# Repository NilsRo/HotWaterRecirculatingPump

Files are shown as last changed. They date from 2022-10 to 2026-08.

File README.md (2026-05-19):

# Recirculation pump automated
How to optimize your water heating with an ESP32.

The project follows the ideas of https://github.com/MakeMagazinDE/Zirkulationspumpensteuerung and http://www.kabza.de/MyHome/CircPump/CirculationPump.php to control the hot water recirculation pump (Warmwasserzirkulationspumpe) via two temperature sensors comparing the warm water flow and return temperature. This saves electricity and thermal energy as the circulation will by done on request and not countinuously.

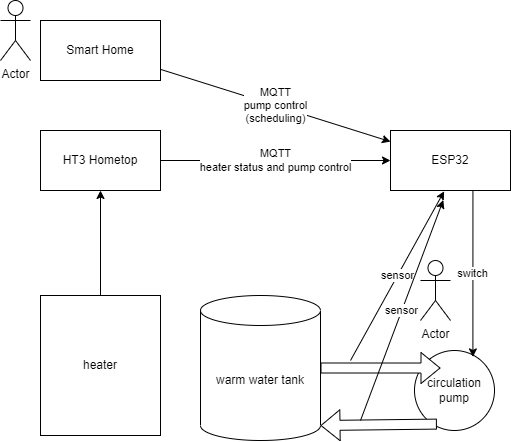
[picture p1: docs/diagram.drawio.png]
diagram


In the HT3 warm water diagram you see the period without warm water taking is flattend so the heater does heatup fewer.

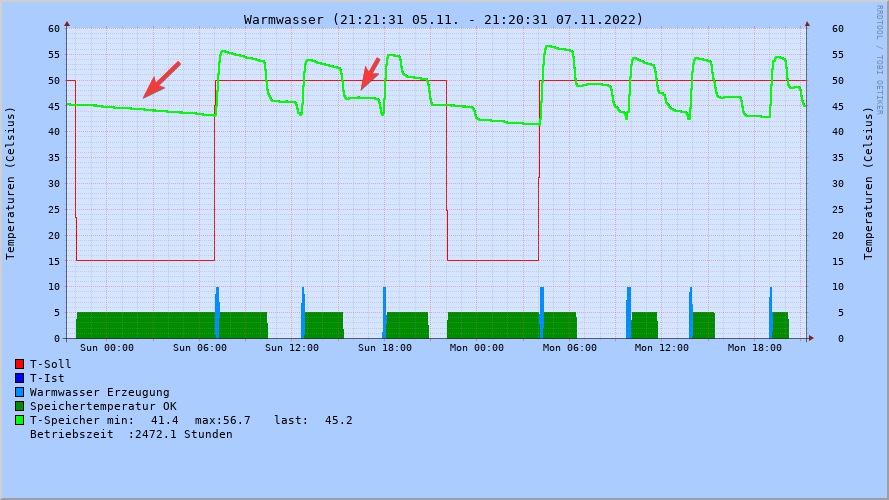
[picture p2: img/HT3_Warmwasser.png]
warm water log


## Featurelist
* Managing the pump via flow and return temperature
* MQTT publishing to get logging information
* MQTT subscription for your smart home and to use heater information like provided by https://github.com/norberts1/hometop_HT3
* Realtime clock for desinfection and logging
* SSD1306 OLED to view status information
* Guided setup to avoid storing WiFi password, etc. in the code
* 2 channel relay to add e.g. a magnetic vent later

## [Hardware](docs/schema.pdf)
* Wemos D1 Mini ESP32
* Standard Arduino/Raspberry 2-channel relay with optokoppler
* [BOM](docs/HotWaterRecirculatingPump.csv)
* STL for [case](docs/Warmwasserpumpe.stl) and [cover](docs/Warmwasserpumpe(2).stl)

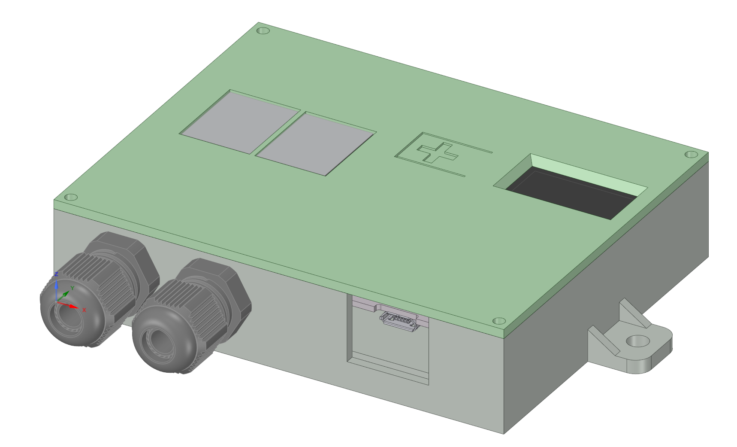
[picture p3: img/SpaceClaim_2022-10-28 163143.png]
Case

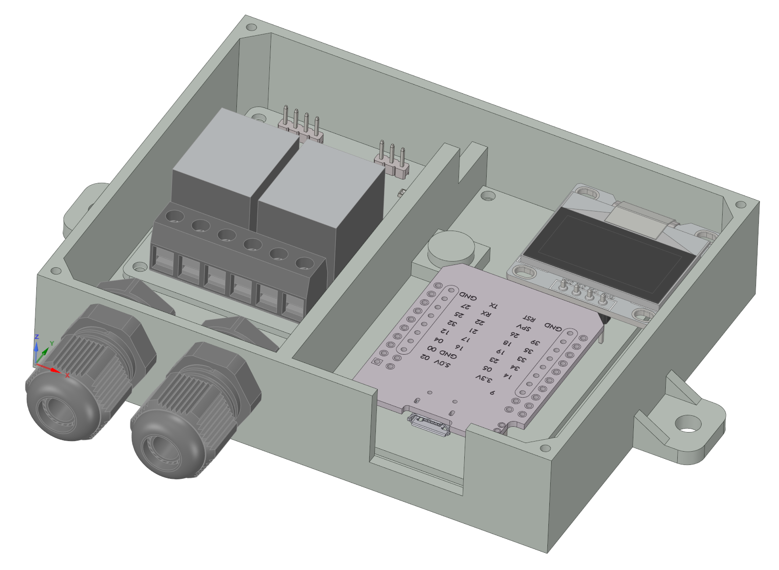
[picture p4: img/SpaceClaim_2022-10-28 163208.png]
Case opened

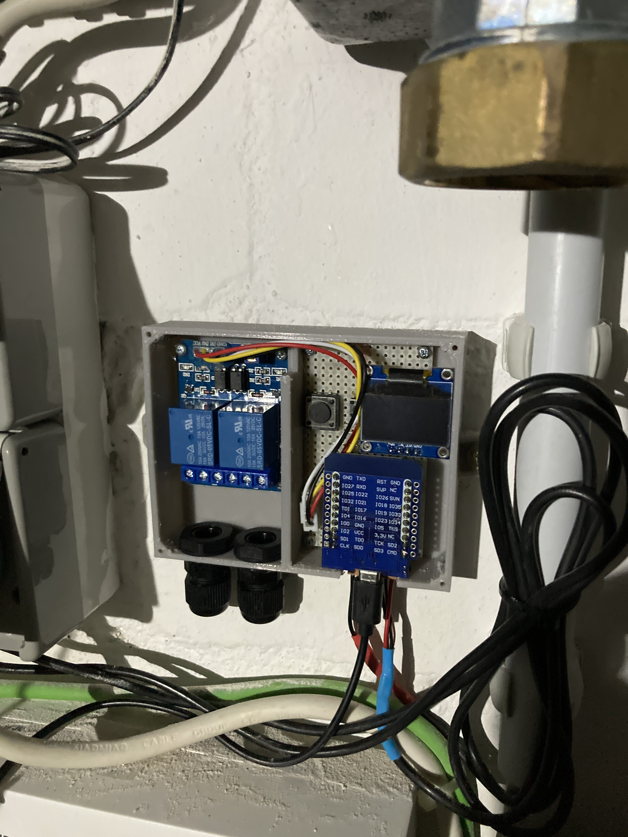
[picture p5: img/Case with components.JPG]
Case with components mounted


## Mounting
The flow sensor have to be mounted 50cm away from the hot water reserviour. The return sensor near the end of the return pipe but not side by side to the reserviour. 

# Software
On first start the thing will open an Access Point named "Zirkulationspumpe" to provide the setup interface. The interface is still available after the device is connected so you can change everything later. But at first the firmware has to be uploaded. You can compile your own version or use the firmware provided in the releases.

1. Do the system configuration and set things name (hostname), AP password (if WiFi connection is lost) and WiFi credentials for your network.
2. MQTT configuration (optional)
   1. publish the following topics (folder structure can be changed):
      * "ww/ht/dhw_Tflow_measured": out temperature of the warm water
      * "ww/ht/dhw_Treturn": return temperature of the warm water circulation
      * "ww/ht/dhw_Tdelta": difference detected in the 5s time window
      * "ww/ht/Tint": system internal temperature
      * "ww/ht/dhw_pump_circulation": pump is running or not
      * "ww/ht/dhw_valve_opened": valve is currently open (true/false)
      * "ww/ht/dhw_valve_sec_opened": how many seconds the valve has been open
      * "ww/ht/dhw_valve_sec_to_refill": seconds until a refill was neccessary. Could be used for alerting purposes if there is a leakage.
      * "ww/ht/dhw_valve_pressure_avg": average system pressure value
      * "ww/ht/status": availability of the system is connected to mqtt broker (Online) or not (Offline)
      * "ww/ht/wifi": wifi related infos like signal quality
      * "ww/ht/sysinfo": status of the system showing the actual mode as Json
        * mode 
          * auto - automatic mode
          * manual - control the pump via the button. The 24h timer to clean the pipes is still running.
        * state
          * heater on - temperature is watched and pump is starting automatically or by MQTT triggers
          * heater off - pump can be started by MQTT triggers
          * desinfection - Desinfection is running, all triggers are blocked until the desinfection is finished by MQTT trigger
          * emergency - some sort of problem detected like with DS18B20. The pump will start by a timer regularly.
      * "ww/ht/info": system information as text
   2. subscribe to heater topics
      * heater status topic (e.g. ht3/hometop/ht/hc1_Tniveau): if the value is matched the system switches to automatic mode. If it is not matched the pump is off and reacts on desinfection and manual starts only.
      * external pump start topic (e.g. ht3/hometop/ht/dhw_pump_circulation):  The event is triggered if the message contains the value set in the configuration. The pump will swtched off if the desired return temperature is reached. Could be used to have a dump switch with HT3 and avoids buying a second IPM module for water pump (automatic mode should be disabled) or much better you can trigger the pump from your smart home or something more advanced.
      * thermal desinfection topic (e.g. ht3/hometop/ht/dhw_thermal_desinfection): if the value is matched the pump will switch on infinitly until another value is received on this topic. This can be used for desinfection topics. If desinfection is switched off the pump will still run until the necessary temperature is reached on the return pipe to guarantee the desinfection of the whole pipe.
3. NTP configuration to get RTC infos for logging (default is fine for german timezone)
4. Temperature configuration to map DS18B20 sensors detected
5. Define your return temperature to switch off when the water is gone through the whole circulation pipe.
6. button short press to swtich screen, button long press for testing the relay/pump.

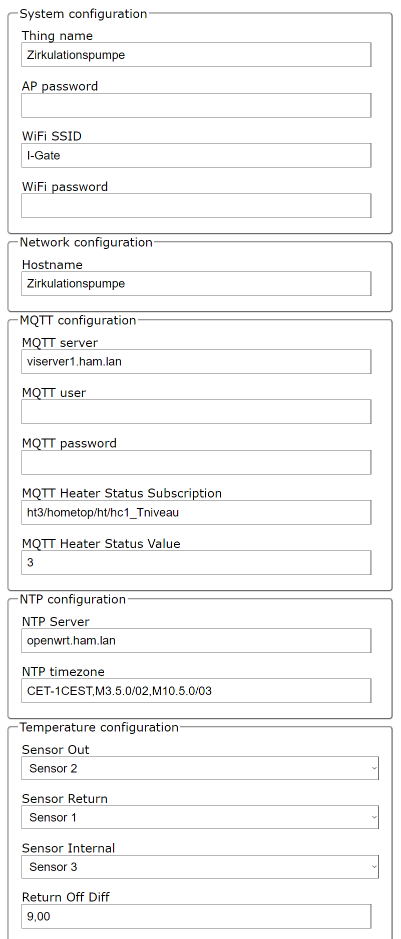
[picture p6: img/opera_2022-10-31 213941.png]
config page


## OLED infos
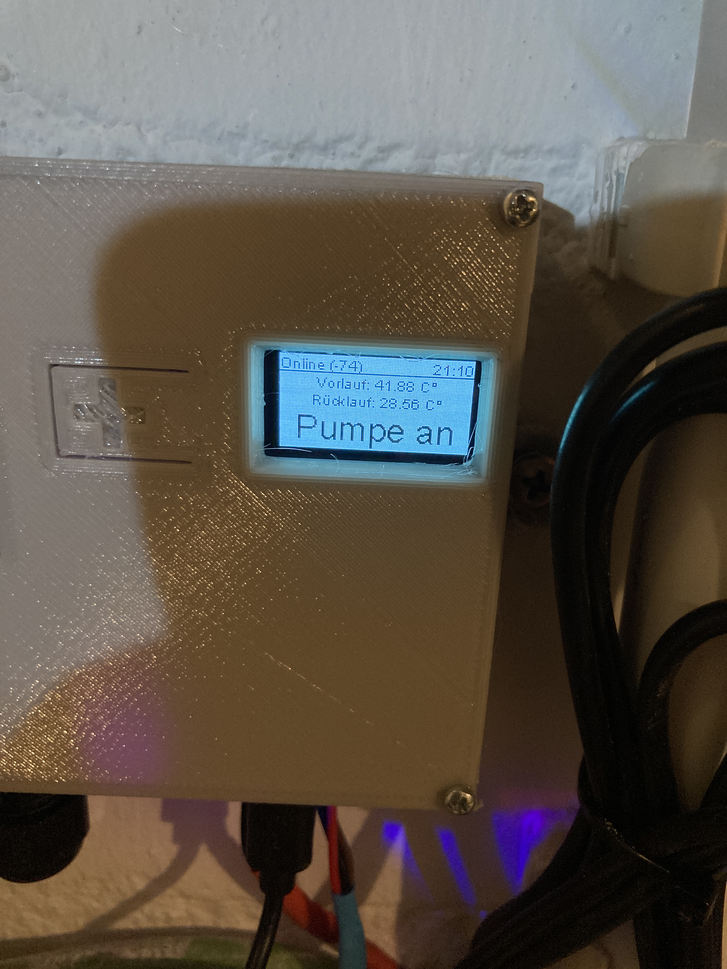
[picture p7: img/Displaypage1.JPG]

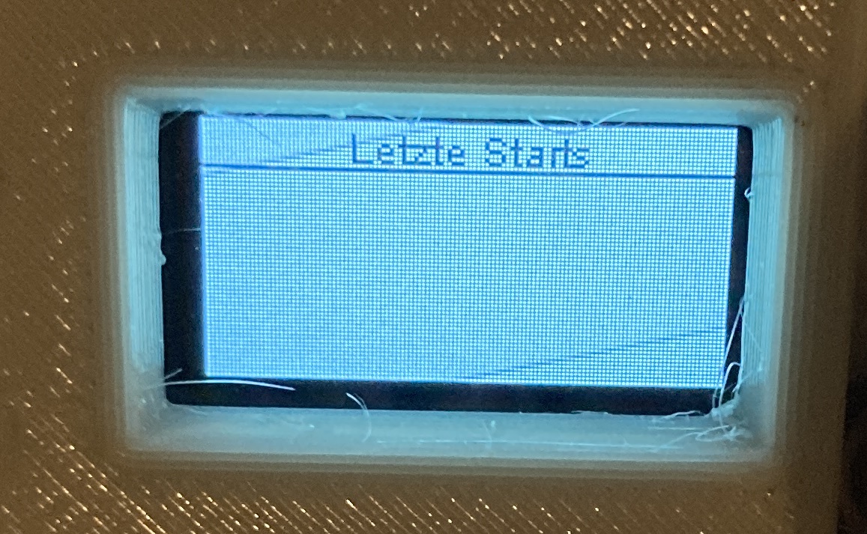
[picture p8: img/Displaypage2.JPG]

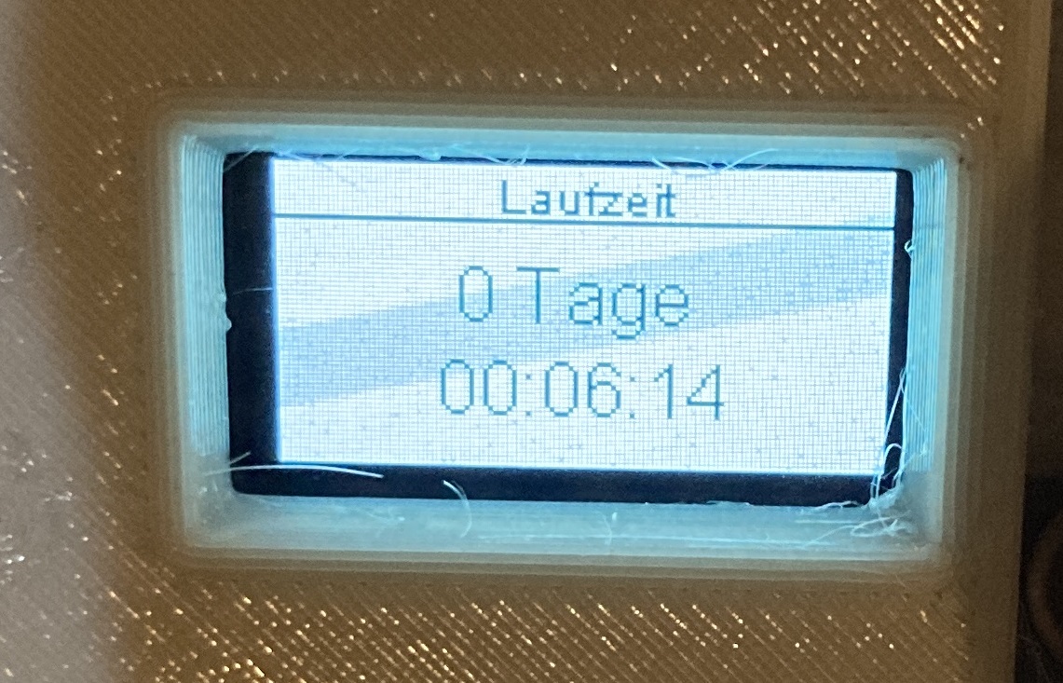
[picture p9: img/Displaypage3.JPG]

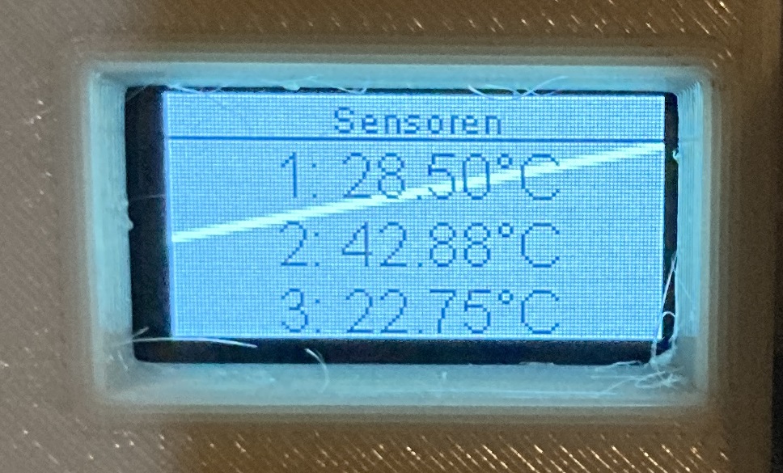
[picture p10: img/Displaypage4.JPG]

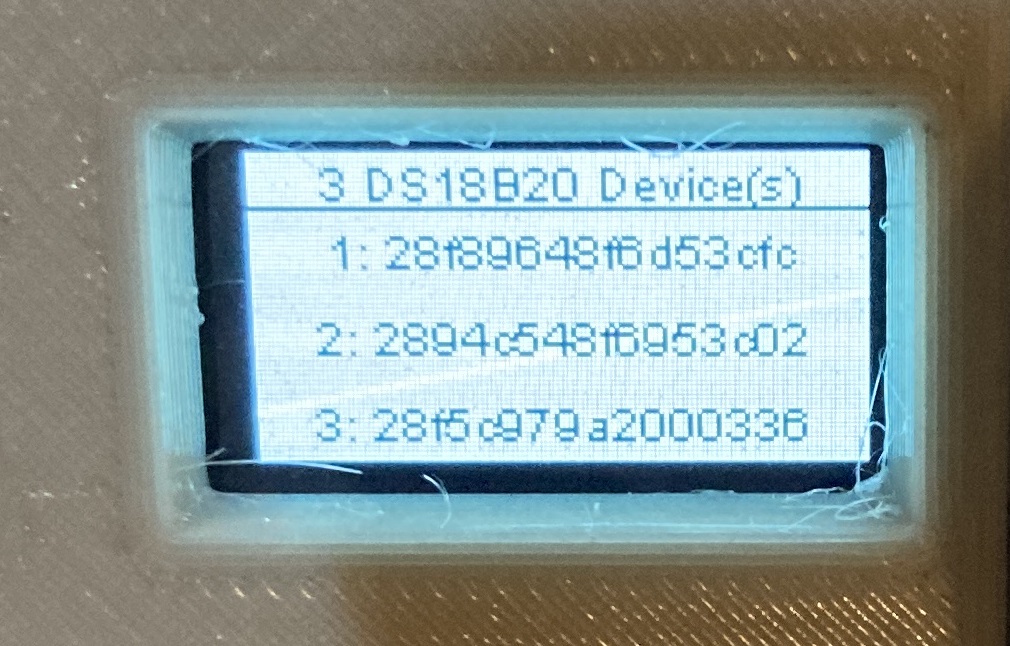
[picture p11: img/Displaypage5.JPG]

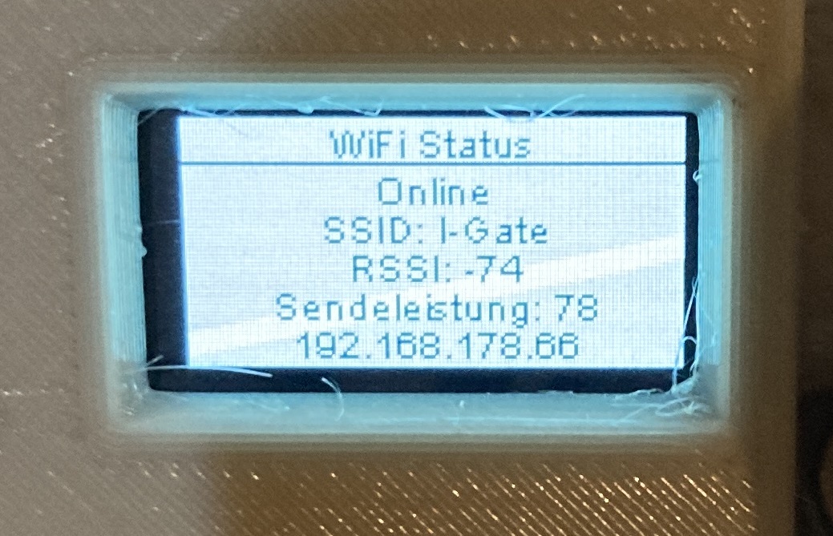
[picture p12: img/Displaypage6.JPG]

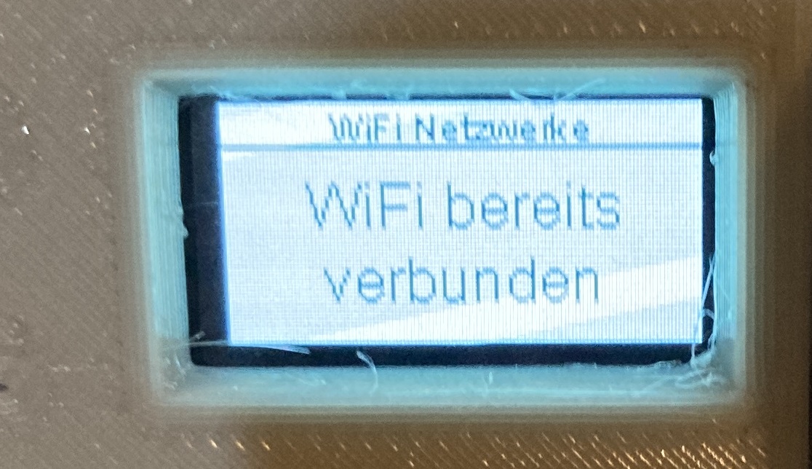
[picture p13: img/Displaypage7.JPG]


# Tips
* Increase the pumps flow to the maximum that the water goes through the pipes as fast as possible.
* Setup special schedules via a smart home (MQTT) if you like to have warm water on request (e.g. by phone) or at a specific time.
* second relay channel is actually unused - suggest how to use it if you need
* If you are using separate networks for IoT devices it is not possible to flash the device with ArduinoOTA as it using broadcast messages that are usually dropped in the firewall. For that setup you should use HTTP upload in the config page to upload the firmware.bin.

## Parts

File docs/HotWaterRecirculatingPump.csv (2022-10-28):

Source: | C:\Users\nrott\Documents\Sync\HomeNils\Modellbau\KiCad\HotWaterRecirculatingPump\HotWaterRecirculatingPump\HotWaterRecirculatingPump.kicad_sch
Date: | 28.10.2022 16:19:44
Tool: | Eeschema (6.0.8)
Generator: | C:\Program Files\KiCad\6.0\bin\scripting\plugins/bom_csv_grouped_by_value.py
Component Count: | 12
Individual Components:
Item | Qty | Reference(s) | Value | LibPart | Footprint | Datasheet
 |  | C1 | 10uF | Device:C |  | ~
 |  | C2 | 470uF | Device:C_Polarized |  | ~
 |  | J1 | Dual Relay | Connector:Conn_01x04_Male | Connector_PinHeader_2.54mm:PinHeader_1x04_P2.54mm_Vertical | ~
 |  | J2 | DS18B20 | Connector:Conn_01x03_Male | Connector_PinHeader_2.54mm:PinHeader_1x03_P2.54mm_Vertical | ~
 |  | J3 | DS18B20 | Connector:Conn_01x03_Male | Connector_PinHeader_2.54mm:PinHeader_1x03_P2.54mm_Vertical | ~
 |  | J4 | BUTTON_LED | Connector:Conn_01x04_Male | Connector_PinHeader_2.54mm:PinHeader_1x04_P2.54mm_Vertical | ~
 |  | LCD1 | SSD1306 | SSD1306:SSD1306 | SSD1306:128x64OLED
 |  | R1 | 1kOhm | Device:R | Resistor_THT:R_Axial_DIN0207_L6.3mm_D2.5mm_P10.16mm_Horizontal | ~
 |  | R2 | 1kOhm | Device:R | Resistor_THT:R_Axial_DIN0207_L6.3mm_D2.5mm_P10.16mm_Horizontal | ~
 |  | SW1 | SW_WIFI_CONF | Switch:SW_Push | Button_Switch_THT:SW_PUSH_6mm_H4.3mm | ~
 |  | U1 | DS18B20 | Sensor_Temperature:DS18B20 | Package_TO_SOT_THT:TO-92_Inline | http://datasheets.maximintegrated.com/en/ds/DS18B20.pdf
 |  | U3 | mini_esp32 | ESP32_mini:mini_esp32 | ESP32_mini:ESP32_mini
Collated Components:
Item | Qty | Reference(s) | Value | LibPart | Footprint | Datasheet
1 | 1 | C1 | 10uF | Device:C |  | ~
2 | 1 | C2 | 470uF | Device:C_Polarized |  | ~
3 | 1 | J1 | Dual Relay | Connector:Conn_01x04_Male | Connector_PinHeader_2.54mm:PinHeader_1x04_P2.54mm_Vertical | ~
4 | 2 | J2, J3 | DS18B20 | Connector:Conn_01x03_Male | Connector_PinHeader_2.54mm:PinHeader_1x03_P2.54mm_Vertical | ~
5 | 1 | J4 | BUTTON_LED | Connector:Conn_01x04_Male | Connector_PinHeader_2.54mm:PinHeader_1x04_P2.54mm_Vertical | ~
6 | 1 | LCD1 | SSD1306 | SSD1306:SSD1306 | SSD1306:128x64OLED
7 | 2 | R1, R2 | 1kOhm | Device:R | Resistor_THT:R_Axial_DIN0207_L6.3mm_D2.5mm_P10.16mm_Horizontal | ~
8 | 1 | SW1 | SW_WIFI_CONF | Switch:SW_Push | Button_Switch_THT:SW_PUSH_6mm_H4.3mm | ~
9 | 1 | U1 | DS18B20 | Sensor_Temperature:DS18B20 | Package_TO_SOT_THT:TO-92_Inline | http://datasheets.maximintegrated.com/en/ds/DS18B20.pdf
10 | 1 | U3 | mini_esp32 | ESP32_mini:mini_esp32 | ESP32_mini:ESP32_mini

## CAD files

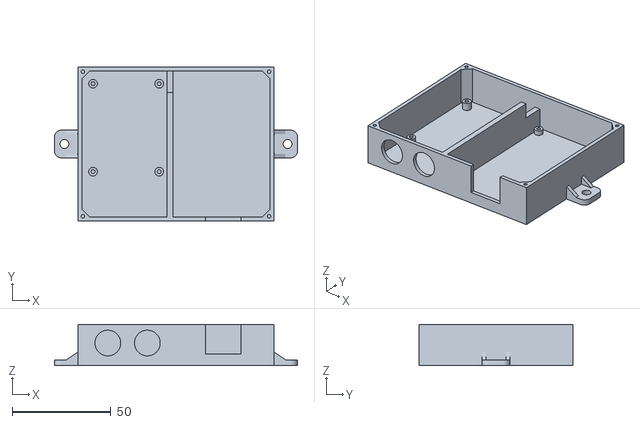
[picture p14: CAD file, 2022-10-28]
docs/Warmwasserpumpe.stl
123.0 x 78.0 x 21.0

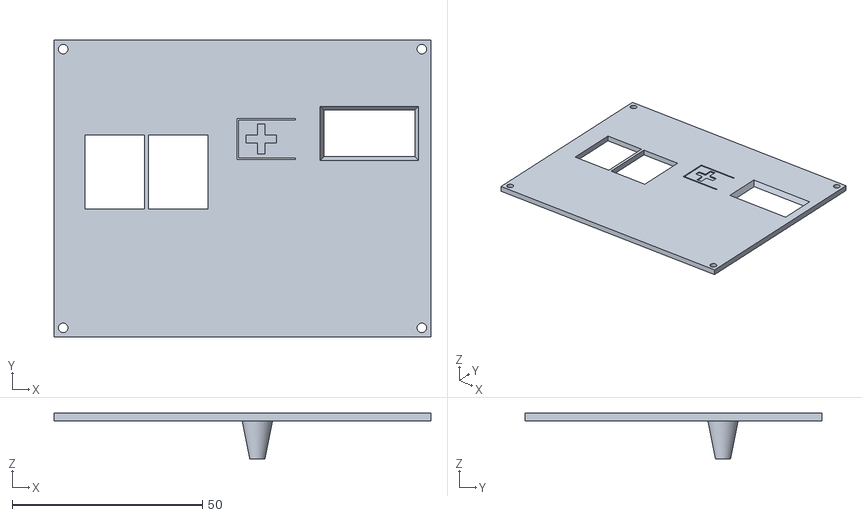
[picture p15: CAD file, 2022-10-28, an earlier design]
docs/Warmwasserpumpe(2).stl
99.0 x 78.0 x 12.0

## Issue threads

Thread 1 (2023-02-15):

MSRC question

andypnz, 2023-02-15:
Hi. Sorry to ask here, but I can't report an issue on your msrc fork...

Have you used a GPS with msrc and a RP 2040? I dont think uart_pio_begin is working in nmea.c (if I add a printf after line 59 in nmea.c it never prints...)

Any ideas appreciated :-)

NilsRo, 2023-02-16:
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

Not an expert for native programming but you should check the uart with an oscilloscope. Perhaps it is the same problem I found with the HW integration. Without the pull-up the communication is not possible and the process method is never called.

andypnz, 2023-02-16:
Hi. Thank you.... I tried the pull ups with no luck.... Seems that with debugging on the PIO falls over - so I have added some LED's to try and figure things out.... Thanks for your suggestions......

Closed 2023-02-19.

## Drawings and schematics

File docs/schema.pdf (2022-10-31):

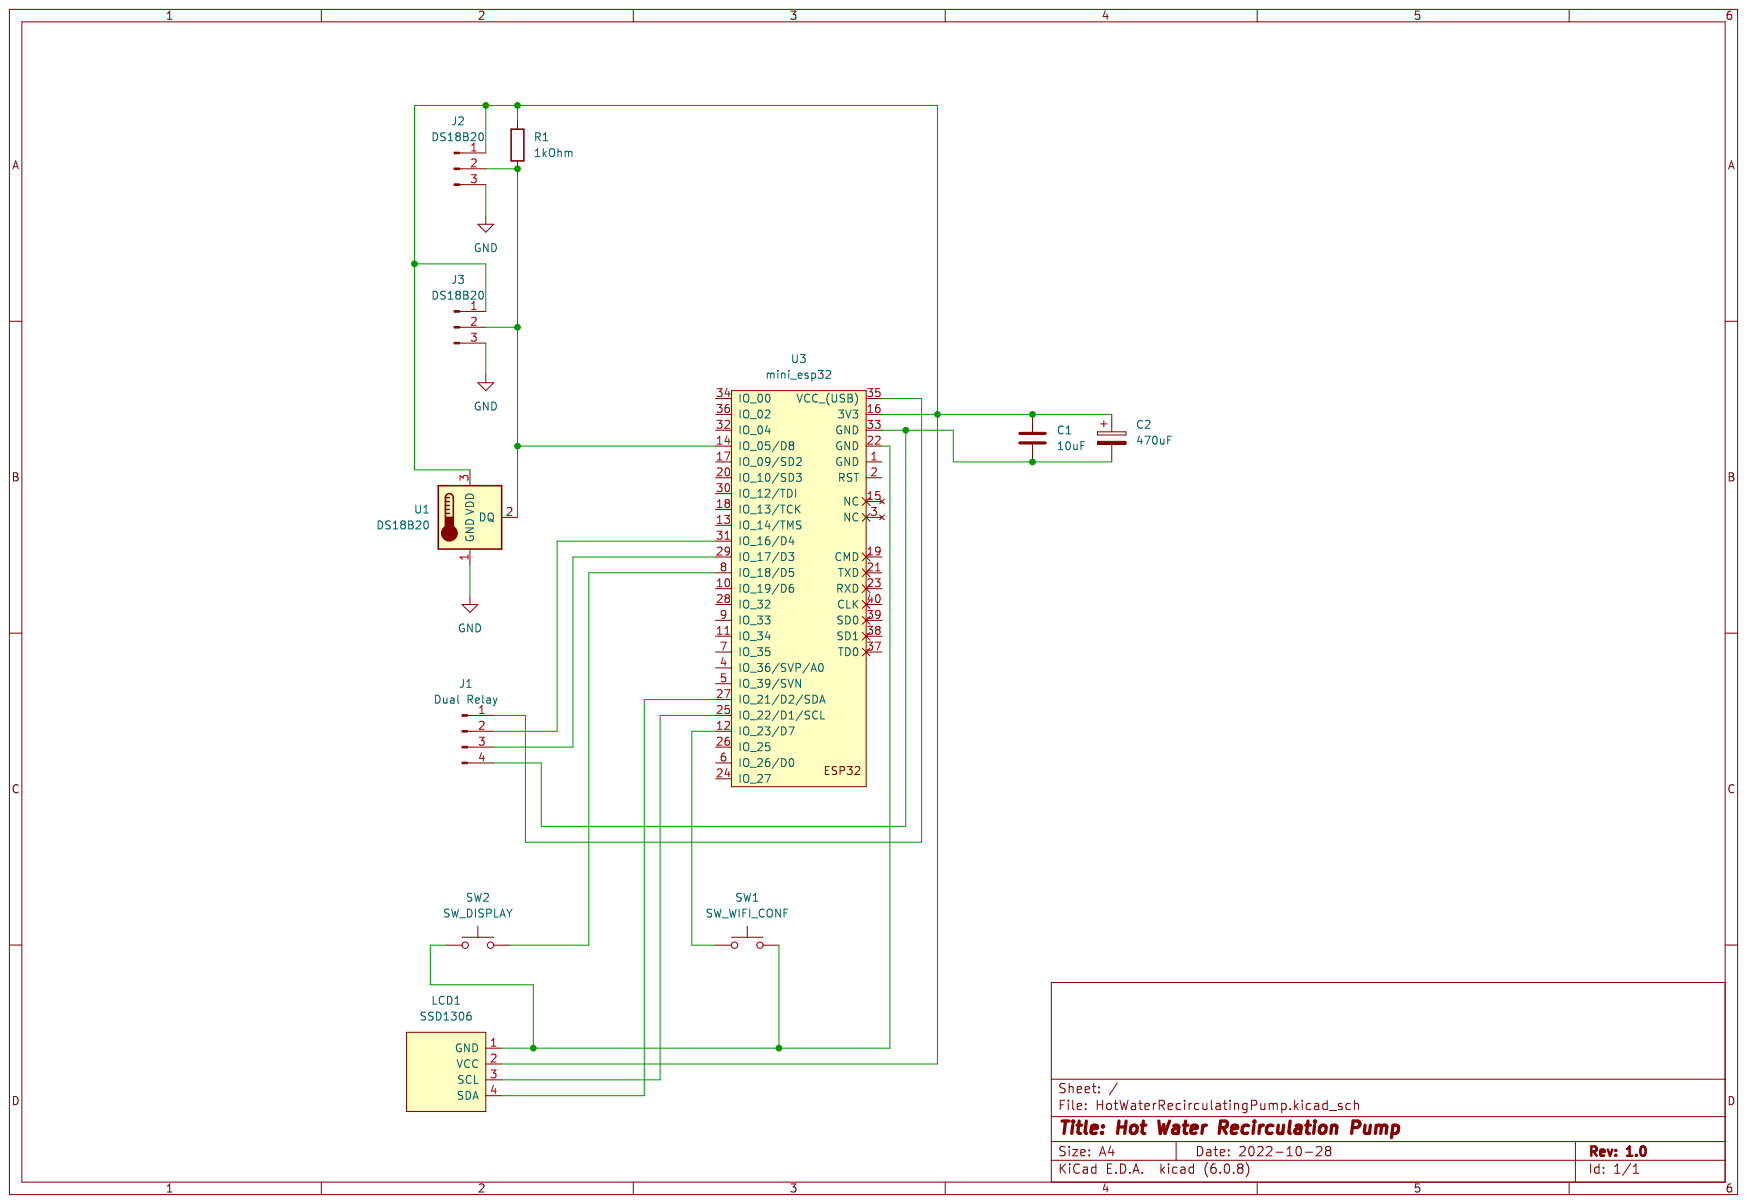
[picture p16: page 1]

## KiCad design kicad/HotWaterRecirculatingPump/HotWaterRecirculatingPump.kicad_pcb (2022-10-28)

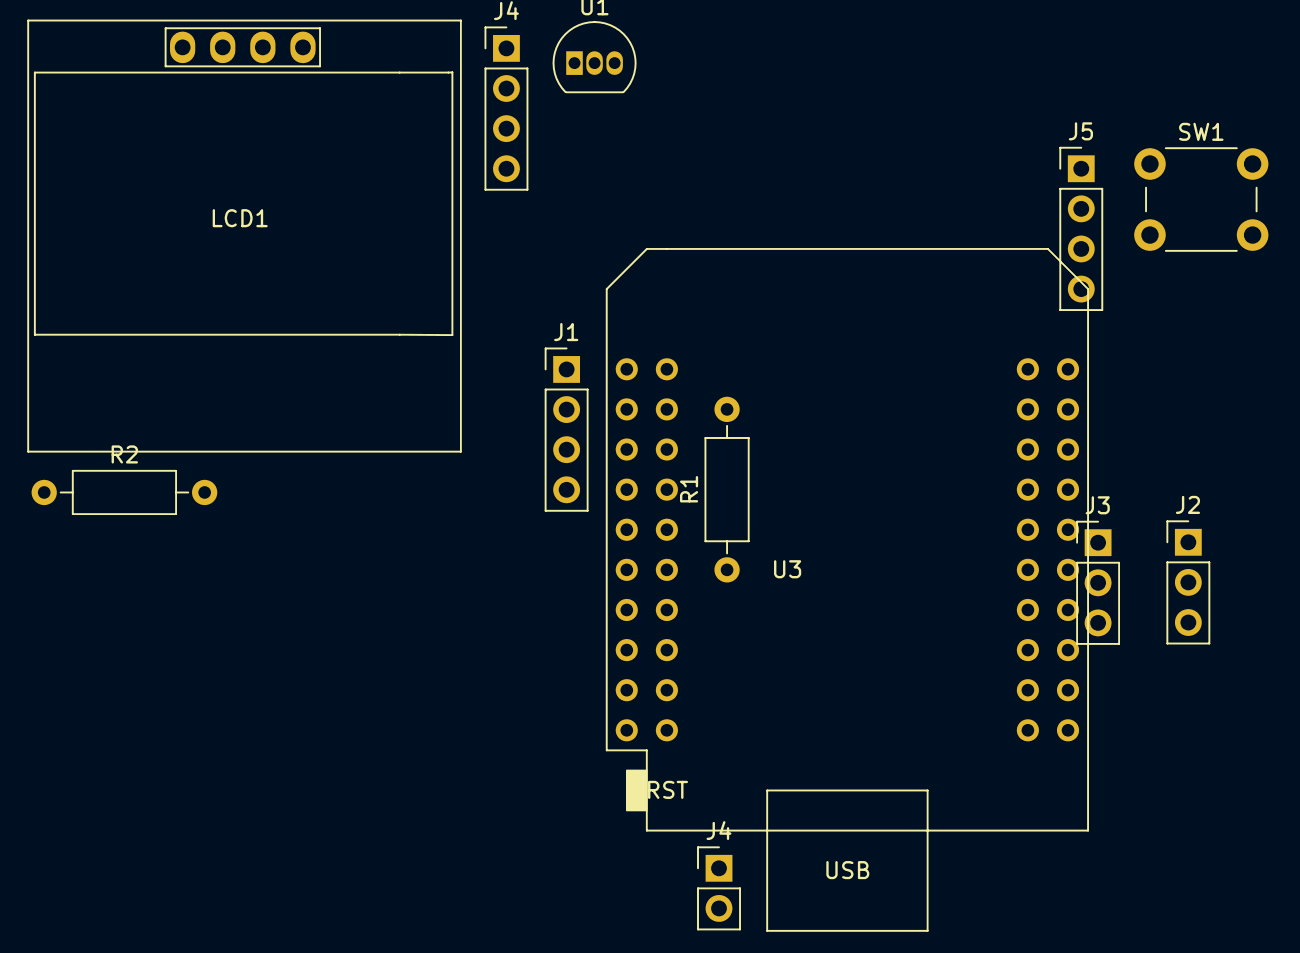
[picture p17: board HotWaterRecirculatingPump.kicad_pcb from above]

Board: 2 copper layers, 12 parts (0 on the bottom side), 15 nets, no tracks yet.

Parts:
J1: Dual Relay; PinHeader_1x04_P2.54mm_Vertical
J2, J3: DS18B20; PinHeader_1x03_P2.54mm_Vertical
J4: SW_DISPLAY_PAGE; PinHeader_1x02_P2.54mm_Vertical
J4#2: BUTTON_LED; PinHeader_1x04_P2.54mm_Vertical
J5: DISPLAY I2C; PinHeader_1x04_P2.54mm_Vertical
LCD1: SSD1306; 128x64OLED
R1, R2: 1kOhm; R_Axial_DIN0207_L6.3mm_D2.5mm_P10.16mm_Horizontal
SW1: SW_WIFI_CONF; SW_PUSH_6mm_H4.3mm
U1: DS18B20; TO-92_Inline
U3: mini_esp32; ESP32_mini

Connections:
GND: J2.3, J3.3, U1.1 (GND)
unnamed: J1.1, U3.35 (VCC_(USB))
unnamed: J1.2, U3.31 (IO_16/D4)
unnamed: J1.3, U3.29 (IO_17/D3)
unnamed: J1.4, U3.33 (GND)
unnamed: J2.1, J3.1, LCD1.2 (VCC), R1.1, U1.3 (VDD), U3.16 (3V3)
unnamed: J2.2, J3.2, R1.2, U1.2 (DQ), U3.14 (IO_05/D8)
unnamed: J4#2.1, J4#2.3, LCD1.1 (GND), SW1.2, U3.22 (GND)
unnamed: J4#2.2, U3.8 (IO_18/D5)
unnamed: J4#2.4, R2.1
unnamed: LCD1.3 (SCL), U3.25 (IO_22/D1/SCL)
unnamed: LCD1.4 (SDA), U3.27 (IO_21/D2/SDA)
unnamed: R2.2, U3.10 (IO_19/D6)
unnamed: SW1.1, U3.12 (IO_23/D7)
unnamed: J4.1, J5.1

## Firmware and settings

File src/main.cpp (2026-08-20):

#include <Arduino.h>
#include <Preferences.h>
#include <nvs.h>
#include <WiFi.h>
#include <OneWire.h>
#include <DallasTemperature.h>
#include <ArduinoJson.h>
#include <Ticker.h>
#include <arduino-timer.h>
#include <AsyncMqttClient.h>
#include <map>
#include <SSD1306Wire.h>
#include <ArduinoOTA.h>
#include <IotWebConf.h>
#include <IotWebConfUsing.h>
#include <IotWebConfTParameter.h>
#include <IotWebConfESP32HTTPUpdateServer.h>
#include <NTPClient.h>
#include <WiFiUdp.h>
#include <time.h>
#include <uptime.h>
#include <algorithm>
#include <OneButton.h>
#include <langu.h>
#include <esp_core_dump.h>
#include <esp_task_wdt.h>
#include <esp_ota_ops.h>
#include <Elog.h>
#include "average.h"

#define STRING_LEN 128
#define DALLASADRESS_LEN 17
#define TEMP_QUEUE_LENGTH 1
#define nils_length(x) ((sizeof(x) / sizeof(0 [x])) / ((size_t)(!(sizeof(x) % sizeof(0 [x])))))
#define RTOSTASKTEMP 1
// #define nils_length( x ) ( sizeof(x) )

static const char *TAG = "HotWaterPump";

// elog
#define LOGID 0
#define LOG_ERR 3
#define LOG_WARNING 4
#define LOG_INFO 6
#define LOG_DEBUG 7

// syslog
char syslogServer[STRING_LEN];
char syslogPortStr[6];
int syslogPort = 514; // default syslog port

// ports
const int ONEWIREPIN = D8;
const int PUMPPIN = D3;
const int VALVEPIN = D4;
const int DISPLAYPIN = D5;
const int WIFICONFIGPIN = D7;

// button
OneButton userBtn(DISPLAYPIN, true);
OneButton resetBtn(WIFICONFIGPIN, true);

// OTA
TaskHandle_t otaTaskHandle = NULL;

bool manualMode = false;
short manualModeCnt = 0;

// pump
static float t[] = {255.0, 255.0, 255.0, 255.0, 255.0}; // letzten 5 Temepraturwerte speichern
bool pumpRunning = false;
unsigned long pumpBlock;
unsigned long pumpStartedAt;
String pump[20] = {"", "", "", "", "", "", "", "", "", "", "", "", "", "", "", "", "", "", "", ""};
unsigned int pumpCnt;
bool pumpCntInit = true;
bool pumpFirstCall = true;

// valve
float valvePressure;
bool valveState = false;
unsigned long valveOpenAt;
unsigned long valveOpenAtTs;
unsigned long valveCloseAt;
unsigned long valveCloseAtTs;
unsigned long valveSecToRefill;
int valveMaxOpen;
char valveMaxOpenStr[4];
bool valveError = false;
bool valveInitFill = false;
SimpleAverage valvePressureAvg(10);
String valveHist[20] = {"", "", "", "", "", "", "", "", "", "", "", "", "", "", "", "", "", "", "", ""};
unsigned int valveHistCnt;
bool valveHistCntInit = true;

// temps
// Queue Handle
TaskHandle_t tempTaskHandle = NULL;
QueueHandle_t tempQueue = NULL;
SemaphoreHandle_t tempSemaphore = NULL;
// Typen
typedef uint8_t DeviceAddress_t[8];
typedef struct
{
  DeviceAddress_t out;
  DeviceAddress_t ret;
  DeviceAddress_t intl;
} SensorIds_t;
typedef struct
{
  float tempOut;
  float tempRet;
  float tempInt;
  bool outConnected;
  bool retConnected;
  bool intConnected;
  TickType_t timestamp; // optional
} TempReport_t;

OneWire oneWire(ONEWIREPIN);
DallasTemperature sensors(&oneWire);
DeviceAddress sensorOut_id;
DeviceAddress sensorRet_id;
DeviceAddress sensorInt_id;
TempReport_t sensorData;

bool sensorError = false;
float tempDiff;
float tempDiffTrigger;
char tempDiffTriggerStr[32];
float mqttTempOut;
float mqttTempRet;
float mqttTempInt;
float mqttTempDiff;
unsigned int checkCnt;

// OLED Display
SSD1306Wire display(0x3C, SDA, SCL); // ADDRESS, SDA, SCL  -  SDA and SCL usually populate automatically based on your board's pins_arduino.h e.g. https://github.com/esp8266/Arduino/blob/master/variants/nodemcu/pins_arduino.h
unsigned int displayPage;
unsigned int displayPageLastRuns = 1;
bool networksPageFirstCall = true;
bool displayState = true;
long displayOnAt;
bool needReset = false;

#define MQTT_PORT 1883
#define MQTT_PUB_TEMP_OUT "dhw_Tflow_measured"
#define MQTT_PUB_TEMP_RET "dhw_Treturn"
#define MQTT_PUB_TEMP_DIFF "dhw_Tdelta"
#define MQTT_PUB_TEMP_INT "Tint"
#define MQTT_PUB_PUMP "dhw_pump_circulation"
#define MQTT_PUB_VALVE_OPENED "dhw_valve_opened"
#define MQTT_PUB_VALVE_SEC_OPENED "dhw_valve_sec_opened"
#define MQTT_PUB_VALVE_SEC_TO_REFILL "dhw_valve_sec_to_refill"
#define MQTT_PUB_VALVE_PRESSURE_AVG "dhw_valve_pressure_avg"
#define MQTT_PUB_STATUS "status"
#define MQTT_PUB_WIFI "log/wifi"
#define MQTT_PUB_INFO "log/info"
#define MQTT_PUB_SYSINFO "log/sysinfo"
AsyncMqttClient mqttClient;
String mqttDisconnectReason;
char mqttDisconnectTime[20];
unsigned long mqttDisconnectTimestamp;
char mqttServer[STRING_LEN];
char mqttUser[STRING_LEN];
char mqttPassword[STRING_LEN];
char mqttTopicPath[STRING_LEN];
static char mqttWillTopic[STRING_LEN];
char mqttHeaterStatusTopic[STRING_LEN];
char mqttHeaterStatusValue[STRING_LEN];
bool mqttHeaterStatus = true;
char mqttPumpTopic[STRING_LEN];
char mqttPumpValue[STRING_LEN];
bool mqttPump;
char mqttValvePressureTopic[STRING_LEN];
String mqttStatus = "";
char mqttThermalDesinfectionTopic[STRING_LEN];
char mqttThermalDesinfectionValue[STRING_LEN];
bool mqttThermalDesinfection = false;

Ticker mqttReconnectTimer;
auto timer = timer_create_default();

WiFiUDP ntpUDP;
NTPClient timeClient(ntpUDP);
char ntpServer[STRING_LEN];
char ntpTimezone[STRING_LEN];
struct tm localTime;

unsigned long nowMillis = 0;

IPAddress localIP;
char hostname[STRING_LEN];
unsigned long lastScan;
int networksFound;
int networksPage;
unsigned int networksPageTotal;
unsigned long displayPageSubChange;
unsigned int langu;

#define CONFIG_VERSION "7"
Preferences preferences;
int iotWebConfPinState = HIGH;
unsigned long iotWebConfPinChanged;
DNSServer dnsServer;
WebServer server(80);
HTTPUpdateServer httpUpdater;
static char chooserValues[][DALLASADRESS_LEN] = {"0", "0", "0"};
static char chooserNames[][STRING_LEN] = {"Sensor 1 NA", "Sensor 2 NA", "Sensor 3 NA"};
static const char languValues[][STRING_LEN] = {"0", "1"};
static const char languNames[][STRING_LEN] = {"German", "English"};
static const char syslogLevelValues[][STRING_LEN] = {"ERROR", "WARNING", "INFO", "DEBUG"};
static const char syslogLevelNames[][STRING_LEN] = {"Error", "Warning", "Info", "Debug"};
IotWebConf iotWebConf("Zirkulationspumpe", &dnsServer, &server, "", CONFIG_VERSION);
IotWebConfParameterGroup mqttGroup = IotWebConfParameterGroup("mqtt", "MQTT");
IotWebConfTextParameter mqttServerParam = IotWebConfTextParameter("server", "mqttServer", mqttServer, STRING_LEN);
IotWebConfTextParameter mqttUserNameParam = IotWebConfTextParameter("user", "mqttUser", mqttUser, STRING_LEN);
IotWebConfPasswordParameter mqttUserPasswordParam = IotWebConfPasswordParameter("password", "mqttPassword", mqttPassword, STRING_LEN);
IotWebConfTextParameter mqttTopicPathParam = IotWebConfTextParameter("topicpath", "mqttTopicPath", mqttTopicPath, STRING_LEN, "ww/ht/");
IotWebConfTextParameter mqttHeaterStatusTopicParam = IotWebConfTextParameter("heater status topic", "mqttHeaterStatusTopic", mqttHeaterStatusTopic, STRING_LEN, "ht3/hometop/ht/hc1_Tniveau");
IotWebConfTextParameter mqttHeaterStatusValueParam = IotWebConfTextParameter("heater status value", "mqttHeaterStatusValue", mqttHeaterStatusValue, STRING_LEN, "3");
IotWebConfTextParameter mqttPumpTopicParam = IotWebConfTextParameter("external pump start topic", "mqttPumpTopic", mqttPumpTopic, STRING_LEN, "ht3/hometop/ht/dhw_pump_circulation");
IotWebConfTextParameter mqttPumpValueParam = IotWebConfTextParameter("external pump start Value", "mqttPumpValue", mqttPumpValue, STRING_LEN, "1");
IotWebConfTextParameter mqttThermalDesinfectionTopicParam = IotWebConfTextParameter("thermal desinfection topic", "mqttThermalDesinfectionTopic", mqttThermalDesinfectionTopic, STRING_LEN, "ht3/hometop/ht/dhw_thermal_desinfection");
IotWebConfTextParameter mqttThermalDesinfectionValueParam = IotWebConfTextParameter("thermal desinfection Value", "mqttThermalDesinfectionValue", mqttThermalDesinfectionValue, STRING_LEN, "1");
IotWebConfTextParameter mqttValvePressureTopicParam = IotWebConfTextParameter("system pressure", "mqttValvePressureTopic", mqttValvePressureTopic, STRING_LEN, "ht3/hometop/ht/ch_system_pressure");
IotWebConfParameterGroup ntpGroup = IotWebConfParameterGroup("ntp", "NTP");
IotWebConfTextParameter ntpServerParam = IotWebConfTextParameter("server", "ntpServer", ntpServer, STRING_LEN, "de.pool.ntp.org");
IotWebConfTextParameter ntpTimezoneParam = IotWebConfTextParameter("timezone", "ntpTimezone", ntpTimezone, STRING_LEN, "CET-1CEST,M3.5.0/02,M10.5.0/03");
IotWebConfParameterGroup valveGroup = IotWebConfParameterGroup("valve", "Valve");
iotwebconf::FloatTParameter valvePressureLowParam = iotwebconf::Builder<iotwebconf::FloatTParameter>("valuePressureLowParam").label("pressure low").defaultValue(1.4).step(0.1).placeholder("e.g. 1.4").build();
iotwebconf::FloatTParameter valvePressureHighParam = iotwebconf::Builder<iotwebconf::FloatTParameter>("valuePressureHighParam").label("pressure high").defaultValue(1.6).step(0.1).placeholder("e.g. 1.6").build();
IotWebConfNumberParameter valveMaxOpenParam = IotWebConfNumberParameter("maximal valve open minutes", "valveMaxOpen", valveMaxOpenStr, 4, "0");
IotWebConfParameterGroup tempGroup = IotWebConfParameterGroup("temp", "Temperature");
iotwebconf::SelectTParameter<DALLASADRESS_LEN> tempOutParam =
    iotwebconf::Builder<iotwebconf::SelectTParameter<DALLASADRESS_LEN>>("tempOutParam").label("out").optionValues((const char *)chooserValues).optionNames((const char *)chooserNames).optionCount(sizeof(chooserValues) / DALLASADRESS_LEN).nameLength(STRING_LEN).build();
iotwebconf::SelectTParameter<DALLASADRESS_LEN> tempRetParam =
    iotwebconf::Builder<iotwebconf::SelectTParameter<DALLASADRESS_LEN>>("tempRetParam").label("return").optionValues((const char *)chooserValues).optionNames((const char *)chooserNames).optionCount(sizeof(chooserValues) / DALLASADRESS_LEN).nameLength(STRING_LEN).build();
iotwebconf::SelectTParameter<DALLASADRESS_LEN> tempIntParam =
    iotwebconf::Builder<iotwebconf::SelectTParameter<DALLASADRESS_LEN>>("tempIntParam").label("internal").optionValues((const char *)chooserValues).optionNames((const char *)chooserNames).optionCount(sizeof(chooserValues) / DALLASADRESS_LEN).nameLength(STRING_LEN).build();
iotwebconf::FloatTParameter tempRetDiffParam = iotwebconf::Builder<iotwebconf::FloatTParameter>("tempRetDiffParam").label("return off diff.").defaultValue(10.0).step(0.5).placeholder("e.g. 23.4").build();
// iotwebconf::FloatTParameter tempDiffTriggerParam = iotwebconf::Builder<iotwebconf::FloatTParameter>("tempDiffTriggerParam").label("temperature trigger").defaultValue(0.125).step(0.0625).placeholder("e.g. 0.12").build();
IotWebConfNumberParameter tempDiffTriggerParam = IotWebConfNumberParameter("temperature trigger", "tempDiffTriggerParam", tempDiffTriggerStr, 32, "0.125", "e.g. 0.125", "step='0.0625'");

IotWebConfParameterGroup miscGroup = IotWebConfParameterGroup("misc", "misc.");
iotwebconf::SelectTParameter<STRING_LEN> languParam =
    iotwebconf::Builder<iotwebconf::SelectTParameter<STRING_LEN>>("languParam").label("language").optionValues((const char *)languValues).optionNames((const char *)languNames).optionCount(sizeof(languValues) / STRING_LEN).nameLength(STRING_LEN).defaultValue("0").build();

IotWebConfParameterGroup syslogGroup = IotWebConfParameterGroup("syslog", "Syslog");
IotWebConfTextParameter syslogServerParam = IotWebConfTextParameter("server", "syslogServer", syslogServer, STRING_LEN, "");
IotWebConfTextParameter syslogPortParam = IotWebConfTextParameter("port", "syslogPort", syslogPortStr, 6, "514");
iotwebconf::SelectTParameter<STRING_LEN> syslogLogLevelParam = iotwebconf::Builder<iotwebconf::SelectTParameter<STRING_LEN>>("syslogLogLevelParam").label("syslog loglevel").optionValues((const char *)syslogLevelValues).optionNames((const char *)syslogLevelNames).optionCount(sizeof(syslogLevelValues) / STRING_LEN).nameLength(STRING_LEN).defaultValue("INFO").build();

/* #region common */
int mod(int x, int y)
{
  return x < 0 ? ((x + 1) % y) + y - 1 : x % y;
}

float roundTo(float value, int decimals)
{
  float factor = pow(10, decimals);
  return roundf(value * factor) / factor;
}
/* #endregion */

/* #region Necessary forward declarations */
String getStatus();
String getWifiJson();
String getSysinfoJson();
void mqttPublish(const char *topic, const char *payload, bool force, bool jsonAddTimstamp);
void mqttSendTopics(bool mqttInit = false);
/* #endregion */

/* #region coredump */
String verbose_print_reset_reason(esp_reset_reason_t reason)
{
  switch (reason)
  {
  case ESP_RST_UNKNOWN:
    return (" Reset reason can not be determined");
  case ESP_RST_POWERON:
    return ("Reset due to power-on event");
  case ESP_RST_EXT:
    return ("Reset by external pin (not applicable for ESP32)");
  case ESP_RST_SW:
    return ("Software reset via esp_restart");
  case ESP_RST_PANIC:
    return ("Software reset due to exception/panic");
  case ESP_RST_INT_WDT:
    return ("Reset (software or hardware) due to interrupt watchdog");
  case ESP_RST_TASK_WDT:
    return ("Reset due to task watchdog");
  case ESP_RST_WDT:
    return ("Reset due to other watchdogs");
  case ESP_RST_DEEPSLEEP:
    return ("Reset after exiting deep sleep mode");
  case ESP_RST_BROWNOUT:
    return ("Brownout reset (software or hardware)");
  case ESP_RST_SDIO:
    return ("Reset over SDIO");
  default:
    return ("NO_MEAN");
  }
}

// void initCoreDumpFlash()
// {
//   if (esp_core_dump_image_check() != ESP_OK)
//   {
//     esp_core_dump_image_erase();
//     Serial.println("Invalid core dump deleted!");
//   }
// }

// bool checkCoreDump()
// {
//   size_t size = 0;
//   size_t address = 0;
//   if (esp_core_dump_image_get(&address, &size) == ESP_OK)
//   {
//     const esp_partition_t *pt = NULL;
//     pt = esp_partition_find_first(ESP_PARTITION_TYPE_DATA, ESP_PARTITION_SUBTYPE_DATA_COREDUMP, "coredump");
//     if (pt != NULL)
//       return true;
//     else
//       return false;
//   }
//   else
//     return false;
// }

String readCoreDump()
{
  size_t size = 0;
  size_t address = 0;
  if (esp_core_dump_image_get(&address, &size) == ESP_OK)
  {
    const esp_partition_t *pt = NULL;
    pt = esp_partition_find_first(ESP_PARTITION_TYPE_DATA, ESP_PARTITION_SUBTYPE_DATA_COREDUMP, "coredump");

    if (pt != NULL)
    {
      uint8_t bf[256];
      char str_dst[640];
      int16_t toRead;
      String return_str;

      for (int16_t i = 0; i < (size / 256) + 1; i++)
      {
        strcpy(str_dst, "");
        toRead = (size - i * 256) > 256 ? 256 : (size - i * 256);

        esp_err_t er = esp_partition_read(pt, i * 256, bf, toRead);
        if (er != ESP_OK)
        {
          Serial.printf("FAIL [%x]\n", er);
          break;
        }

        for (int16_t j = 0; j < 256; j++)
        {
          char str_tmp[3];

          sprintf(str_tmp, "%02x", bf[j]);
          strcat(str_dst, str_tmp);
        }

        return_str += str_dst;
      }
      return return_str;
    }
    else
    {
      return "Partition NULL";
    }
  }
  else
  {
    return "esp_core_dump_image_get() FAIL";
  }
}

void crash_me_hard()
{
  // provoke crash through writing to a nullpointer
  volatile uint32_t *aPtr = (uint32_t *)0x00000000;
  *aPtr = 0x1234567; // goodnight
}

void startCrashTimer(int secs)
{
  for (int i = 0; i <= secs; i++)
  {
    printf("Crashing in %d seconds..\n", secs - i);
    vTaskDelay(1000 / portTICK_PERIOD_MS);
  }
  printf("Crashing..\n");
  vTaskDelay(1000 / portTICK_PERIOD_MS);
  crash_me_hard();
}

void startCrash()
{
  String s = "<!DOCTYPE html><html lang=\"en\"><head><meta name=\"viewport\" content=\"width=device-width, initial-scale=1, user-scalable=no\"/>";
  s += iotWebConf.getHtmlFormatProvider()->getStyle();
  s += "<title>Warmwater Recirculation Pump</title>";
  s += iotWebConf.getHtmlFormatProvider()->getHeadEnd();
  s += "Crashing in 5 seconds...!";
  s += iotWebConf.getHtmlFormatProvider()->getEnd();
  server.send(200, "text/html", s);
  startCrashTimer(5);
}

void handleCoreDump()
{
  server.sendHeader("Content-Type", "application/octet-stream");
  server.sendHeader("Content-Disposition", "attachment; filename=coredump.bin");
  server.sendHeader("Connection", "close");
  server.send(200, "application/octet-stream", readCoreDump());
}

void handleDeleteCoreDump()
{
  String s = "<!DOCTYPE html><html lang=\"en\"><head><meta name=\"viewport\" content=\"width=device-width, initial-scale=1, user-scalable=no\"/>";
  s += iotWebConf.getHtmlFormatProvider()->getStyle();
  s += "<title>Warmwater Recirculation Pump</title>";
  s += iotWebConf.getHtmlFormatProvider()->getHeadEnd();
  if (esp_core_dump_image_erase() == ESP_OK)
    s += "Core dump deleted";
  else
    s += "No core dump found!";
  s += "<p><button type=\"button\" onclick=\"javascript:history.back()\">Back</button>";
  s += iotWebConf.getHtmlFormatProvider()->getEnd();
  server.send(200, "text/html", s);
}
/* #endregion */

/* #region watchdog */
void handleCrashCounter()
{
  // Reset-Gründe prüfen
  esp_reset_reason_t reason = esp_reset_reason();
  bool isCrash =
      reason == ESP_RST_TASK_WDT ||
      reason == ESP_RST_WDT ||
      reason == ESP_RST_PANIC ||
      reason == ESP_RST_BROWNOUT;

  Preferences prefs;
  prefs.begin("sys", false);
  int crashCounter = prefs.getInt("crashCounter", 0);

  if (crashCounter >= 10)
  {
    Logger.log(LOGID, ELOG_LEVEL_ERROR, "Device has crashed %d times in a row. Initiating failover to backup partition.", crashCounter);
    // clear persisted counter before switching partition to avoid replay loops
    prefs.putInt("crashCounter", 0);
    prefs.end();

    const esp_partition_t *next = esp_ota_get_next_update_partition(NULL);
    esp_ota_set_boot_partition(next);
    esp_restart();
  }

  if (isCrash)
  {
    // Increment persisted counter so it survives panics
    crashCounter++;
    prefs.putInt("crashCounter", crashCounter);
    Logger.log(LOGID, ELOG_LEVEL_INFO, "Reset reason: %s, persisted crashCounter: %d", verbose_print_reset_reason(reason).c_str(), crashCounter);
  }
  else if (reason == ESP_RST_SW)
  {
    // Software reset: preserve persisted counter
    Logger.log(LOGID, ELOG_LEVEL_INFO, "Software reset, preserved persisted crashCounter: %d", crashCounter);
  }
  else
  {
    // Normal boot -> clear persisted counter
    crashCounter = 0;
    prefs.putInt("crashCounter", crashCounter);
    Logger.log(LOGID, ELOG_LEVEL_INFO, "Normal boot, cleared persisted crashCounter");
  }
  prefs.end();
}
/* #endregion */

/* #region NVS handling*/
void changeNvsMode(bool readOnly)
{
  static bool nvsStatus = false;
  if (nvsStatus)
  {
    preferences.end();
  }
  if (preferences.begin("settings", readOnly))
    nvsStatus = true;
  else
  {
    Logger.log(LOGID, ELOG_LEVEL_ERROR, "Error opening NVS-Namespace");
    for (;;)
      ; // leere Dauerschleife -> Ende
  }
}

void saveValveTimestampNvs(const char *prefKey, unsigned long value)
{
  changeNvsMode(false);
  preferences.putULong(prefKey, value);
  changeNvsMode(true);
}
/* #endregion */

/* #region logging */
void applySyslogLogLevel(const char *level)
{
  if (strcmp(level, "ERROR") == 0)
    Logger.setSyslogLogLevel(LOGID, ELOG_LEVEL_ERROR, ELOG_FAC_SYSLOG);
  else if (strcmp(level, "WARNING") == 0)
    Logger.setSyslogLogLevel(LOGID, ELOG_LEVEL_WARNING, ELOG_FAC_SYSLOG);
  else if (strcmp(level, "INFO") == 0)
    Logger.setSyslogLogLevel(LOGID, ELOG_LEVEL_INFO, ELOG_FAC_SYSLOG);
  else if (strcmp(level, "DEBUG") == 0)
    Logger.setSyslogLogLevel(LOGID, ELOG_LEVEL_DEBUG, ELOG_FAC_SYSLOG);
  else
    Logger.setSyslogLogLevel(LOGID, ELOG_LEVEL_INFO, ELOG_FAC_SYSLOG); // default

  Serial.printf("Elog syslog level set to %s\n", level);
  Logger.log(LOGID, ELOG_LEVEL_INFO, "Elog syslog level set to %s", level);
}
/* #endregion */
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
void loop()
{
  // esp_task_wdt_reset();
  nowMillis = millis();
  ArduinoOTA.handle();
  iotWebConf.doLoop();
  timer.tick();
  userBtn.tick();
  resetBtn.tick();

  if (needReset)
  {
    Logger.log(LOGID, ELOG_LEVEL_INFO, "Rebooting in 1 second.");
    iotWebConf.delay(1000);
    ESP.restart();
  }

  if (!manualMode && displayState && 60000 < nowMillis - displayOnAt)
  { // switch display off after 10mins
    displayOff();
  }
}

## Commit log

2022-10-12 Added diaplay pages, NTP Server, Last pumps page,
2022-10-13 Corrected display, added hystersis to check loop and avoided delay
    [main.cpp]
2022-10-15 Corrected Button handling
2022-10-18 Sensorerror in MQTT added
2022-10-28 Corrected display page 2
    [main.cpp]
2022-10-28 WiFi Output power to maximum
2022-10-28 Update schema.pdf
    Added capacitors to schematics to avoid brownout
2022-10-28 Kicad, README, BOM, pictures
    [HotWaterRecirculatingPump.csv, HotWaterRecirculatingPump.kicad_pcb, HotWaterRecirculatingPump.kicad_sch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]
2022-10-28 Gitignore for Kicad
2022-10-28 Formatting, added manual pump switch
2022-10-29 Wifi scan working
    [HotWaterRecirculatingPump.kicad_sch]
2022-10-29 5 last pumpaction in HTML view
2022-10-29 Last Pump Actions corrected
    [main.cpp]
2022-10-30 Array Length function, Pump First Call
2022-10-30 Corrected order of last pump actions
    [main.cpp]
2022-10-31 MQTT Subscription for heater status
2022-10-31 fixed heater status
2022-10-31 Fix HeaterStatus, MQTT optimization
    [main.cpp]
2022-11-01 Added external pump trigger
2022-11-01 fixed empty subscripton handling
    [main.cpp]
2022-11-02 MQTT config bug, WiFi Workaround
    [main.cpp]
2022-11-02 fix string compare MQTT
    [main.cpp]
2022-11-02 optimized pumpOff after activation
2022-11-06 Workaround for WiFi Settings with preferences
    [main.cpp]
2023-01-22 Chenged Disinfection timer to millis compare
2023-04-03 - MQTT Publish centralized - added topic path as parameter - Corrected date display in log
    [main.cpp]
2023-04-07 MQTT correction, added more info to status page
    [main.cpp]
2023-04-20 Added error codes for unexpected reset
    [main.cpp]
2023-04-23 Optimized MQTT handling on reconnect Added Core Dump function
    [partitions.csv]
2023-04-24 Fixed thermal desinfection mqtt mode
    [main.cpp]
2023-05-03 - Status changed - Typos in status page - trigger handling fixed if heater is off
    [main.cpp]
2023-06-15 Added exception decoder MQTT trigger will trigger pump everytime
2023-12-02 Corrected log output if settings are restored
    [main.cpp]
2023-12-02 settings restore corrected (Ap Password)
    [main.cpp]
2024-12-04 Better "healing" in case of a sensor error
    [main.cpp]
2024-12-05 Read temp even if there is a sensor error
    [main.cpp]
2024-12-16 - Added sensor info to mqtt - fixed assignment of sensors to function - status topic added - old status topic renamed to sysinfo
    [main.cpp]
2024-12-18 Issue with last will of MQTT Client - broken connection
    [main.cpp]
2024-12-18 Update ArduinoJson
2024-12-19 - Activated LastWill Topic - Updated ArduinoJson handling
2025-10-13 Activated second relay to control a valve via MQTT
2025-10-26 Added valve and tested behavior
2025-11-18 Valve Texts
2025-11-18 Added feature for automatic refill of heater system
2025-11-24 Added arduino-timer to avoid conflicts with interrupt based timers
    [main.cpp]
2025-11-24 Corrected Serial log output
    [main.cpp]
2025-11-25 Added average pressure Added new sysinfo format
2025-11-27 Correct OTA flash partition layout
    [partitions.csv]
2025-11-27 Corrected syslog Changed 10min to 1min timer for better pressure adoption
    [main.cpp]
2025-11-27 Added HTML pressure vs pressure avg
2025-12-01 Added pressure to display
2026-02-07 Added init fill to handle low pressure after reset
    [main.cpp]
2026-02-12 Valve history, float compare correction
    [main.cpp]
2026-04-09 Reduced calls to 1-Wire Bus
2026-04-16 Moved 1-Wire to CPU Thread 1
2026-05-02 Disabled EDF Coredump because of incompatibility to Arduino Framework
    [main.cpp]
2026-05-02 Fix HexStr2Arr conversion length (overflow)
    [main.cpp]
2026-05-02 - IDF bootloader to handle OTA partitions - watchdog for arduino loop - crash counter for partition switch
    [main.cpp]
2026-05-05 - changed logging to ESP_LOG - added syslog logging - changed button handling to OneButton library - hamonized manual mode between valve and pump
2026-05-05 Corrected OTA partition selection
    [main.cpp]
2026-05-05 If manual mode is on never switch of display to recognize it
2026-05-05 Changed logging to direct UART access
2026-05-05 Corrected display on/off handling Added native UART driver for logging
    [main.cpp]
2026-05-15 Changed Logging to elog lib as ESP_LOG is not supported in Arduino Framework
2026-05-15 Automatic failover to backup partition after 10 panics
    [main.cpp]
2026-05-16 Secured ArduinoOTA with local AP password
2026-05-19 Added valve refill to README
2026-08-19 Fixed MQTT client id empty
    [main.cpp]
2026-08-19 Transfer 1-Wire data to internal structures every second
2026-08-19 Moved display refresh into loop timer instead of unnecessary interrupt timer.
2026-08-19 Corrected resetBtn PIN link
    [main.cpp]
